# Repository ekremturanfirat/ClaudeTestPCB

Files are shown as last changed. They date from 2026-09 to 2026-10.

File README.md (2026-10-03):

# PCBDesignWClaude — 3-Phase BLDC ESC (ESP32-WROOM-32E)

KiCad project for a 3-phase brushless motor ESC.

- **MCU:** ESP32-WROOM-32E, soldered SMD directly onto the PCB (no plug-in module)
- **Input:** 12–36V DC
- **Target continuous phase current:** ~5–10A
- **Control/telemetry:** UART + CAN bus
- Design follows [METU PowerLab PCB design rules](https://github.com/odtu/Powerlab/blob/master/KiCAD/PCB_DESIGN_RULES.md)
  and uses parts exclusively from [PowerLabKiCadLibraries](https://github.com/odtu/PowerLabKiCadLibraries).

## Status
- [x] GitHub repo created
- [x] ESP32-WROOM-32E added to PowerLabKiCadLibraries (odtu/PowerLabKiCadLibraries#2, merged)
- [x] Library additions + fixes (power symbols, mounting holes, fiducials, test pads, net ties, ESP32 footprint fix): odtu/PowerLabKiCadLibraries#3 (merged)
- [x] Schematic Rev B: full rebuild per the PowerLab rules; kicad-cli ERC 0 errors, netlist verified (see [hardware/ARCHITECTURE.md](hardware/ARCHITECTURE.md))
- [x] Library fixes found during layout (exposed pads, mask margins, logo/QR graphics, ESP32 3D model): odtu/PowerLabKiCadLibraries#5 (merged)
- [x] PCB Rev B: 4 layers, 100 × 90 mm; kicad-cli DRC 0 errors / 0 unconnected / 0 parity (see [hardware/ARCHITECTURE.md](hardware/ARCHITECTURE.md#pcb-rev-b))
- [x] Fab outputs: Gerber + drill zip, BOM, position file, assembly drawings in [hardware/fab](hardware/fab/README.md)

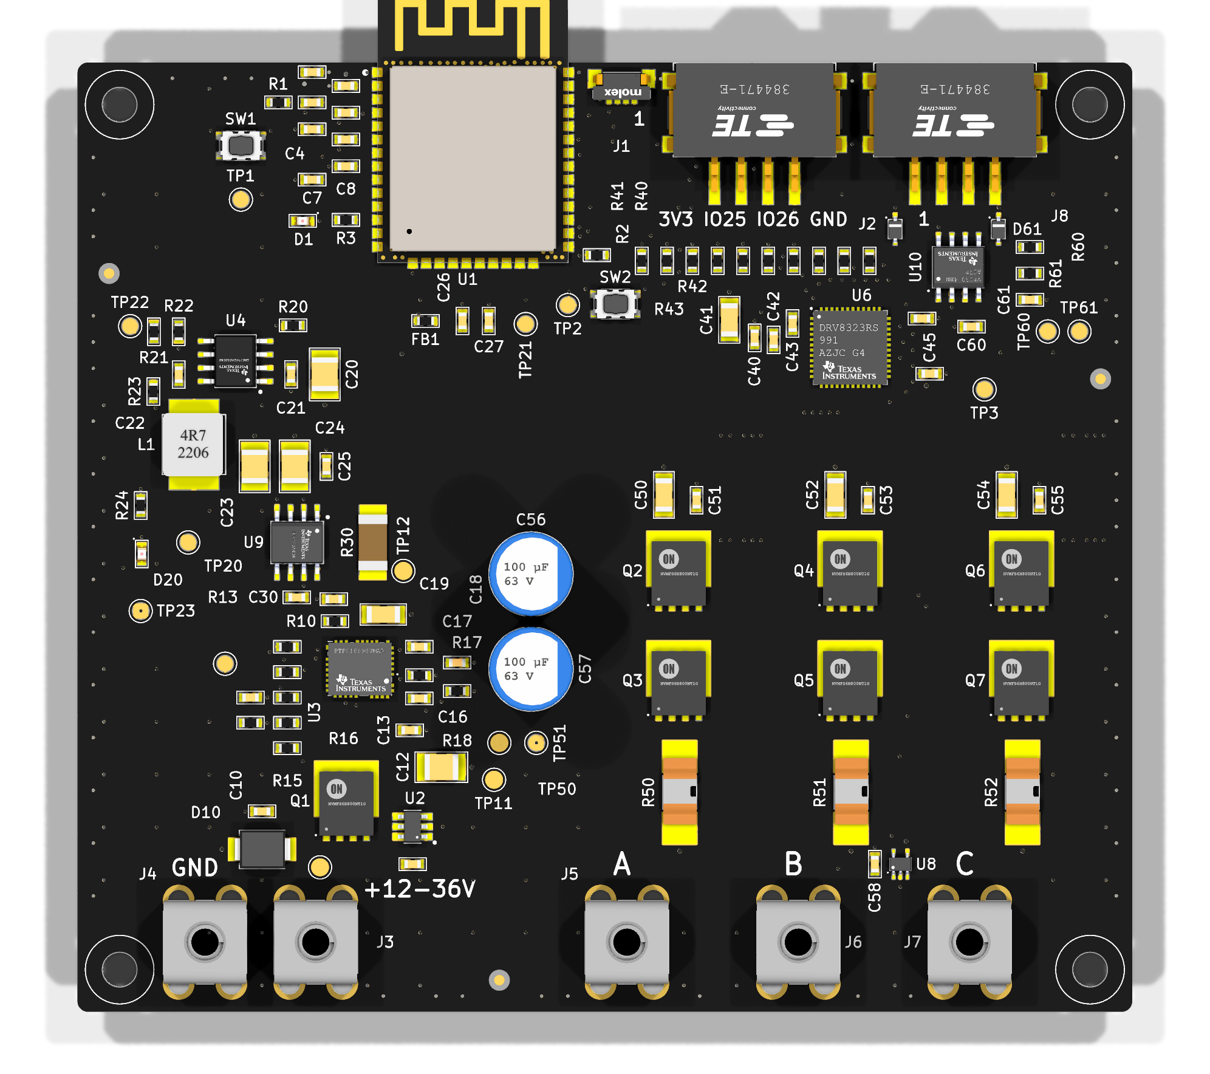
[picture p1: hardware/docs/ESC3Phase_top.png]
PCB top


## Layout
- `hardware/` — KiCad project

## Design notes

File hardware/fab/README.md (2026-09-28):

# ESC3Phase Rev B — fabrication and assembly files

Generated with kicad-cli 10.0.5 from `../ESC3Phase.kicad_pcb`. DRC with schematic parity passed with
0 errors, 0 unconnected items and 0 parity issues. Two warnings remain: the ESP32 silk outline runs over the
antenna overhang.

## Files
| File | Use |
|---|---|
| `ESC3Phase_Gerber_Drill_RevB.zip` | Upload this to PCBWay. It contains the Gerbers, the Excellon drill files (PTH and NPTH), the drill maps and the Gerber job file. |
| `gerber/` | The same files unzipped. |
| `ESC3Phase_BOM.csv` | BOM grouped by value, footprint and MPN. Columns: reference, quantity, value, manufacturer, MPN, package, SMD/THT, Digi-Key, Mouser, footprint, note. UTF-8 with BOM, so Excel shows "µ" correctly. |
| `ESC3Phase_pos.csv` | Position file (centroids) for the 102 SMD parts, top side. Units are mm; the origin is the bottom-left board corner and Y points up. |
| `ESC3Phase_assembly_top.pdf` / `_bottom.pdf` | Assembly drawings: Fab + silk + outline at 1.4×. They show the 25 references that have no room on the silkscreen. |

All outputs share one origin, the board's bottom-left corner (the drill/place origin).

## PCB order (PCBWay)
| Option | Value |
|---|---|
| Size | 100 × 90 mm, 1 mm corner radius |
| Layers | **4** (the only option above the standard-price spec, approved) |
| Stackup | 1.6 mm FR-4 TG150–160: L1 / 0.2 mm prepreg / L2 / 1.04 mm core / L3 / 0.2 mm prepreg / L4 |
| Copper | 1 oz outer, 1 oz inner |
| Min track / space | 0.15 / 0.2 mm (6/6 mil class). One 0.15 mm neck-down; everything else is ≥ 0.2 mm |
| Min hole | 0.3 mm (445 plated holes, 8 non-plated) |
| Solder mask / silk | green / white |
| Surface finish | HASL lead-free |
| Vias | tented, except the thermal vias in exposed pads, which are open on the pad side |
| Extras | none: no impedance control, castellations or blind vias |

## Assembly
- **Parts:** 109 in total, 102 SMD (all on top) and 7 THT: C56/C57 bulk caps and J3–J7 screw terminals. Only top-side paste is needed; the bottom paste layer is empty.
- **Breakaway rails needed for machine assembly.** The ESP32 antenna overhangs the top edge, and the connectors and terminals sit within 3.5 mm of the top and bottom edges. Add the rails when panelizing.
- **Fiducials:** 3 global fiducials on top.
- **BOM notes:**
  - **C3, C44 and C42 (1 µF):** order by the MPN (Murata GRM188D72A105KE01D, 0603, 100 V). The Digi-Key and Mouser numbers in the library point to a different part (a Samsung 1210). That's a library data issue.
  - **R60, R61 and C61 (CAN split termination):** fit them only on the two nodes at the ends of the bus. Leave them unfitted (DNP) on every other node.
- **Hand soldering:** power pads and the screw terminals connect solid to their pours, so use a large iron tip.

## Before ordering
- Check the Gerbers in a Gerber viewer (KiCad GerbView or PCBWay's online viewer).
- Print the layout 1:1 and check the footprints against the real parts (rule 3.7).
- Scan the QR code on the bottom silk (see `../docs/ESC3Phase_bottom.png`).

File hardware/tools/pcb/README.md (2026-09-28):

# PCB generation scripts (Rev B)

The Rev B board was built from KiCad's netlist with these scripts (KiCad 10.0.5 Python + kicad-cli,
Freerouting 2.4.1 on Java 25). They document how every placement, pour, hand-routed net and rule came about.

| Step | Script |
|---|---|
| Placement (floor plan, parts at their pins) | `placement.py`, `pcb_build.py`, `place_check.py` |
| Project file: schematic settings + board settings + net classes (HV) | `pro_merge.py` |
| Power pours, GND planes, Kelvin keep-outs, fan-out rule areas | `power.py` |
| Hand routing: DRV8323 gate drive and fan-outs, Kelvin taps, local links, GND vias | `prep_route.py` |
| Freerouting input (pours as keepouts, complete nets reduced) / session import | `dsn_prep.py`, `ses_import.py` |
| Post-route: widths, L3 GND fill + stitching, stackup, silk, board info | `fix_widths.py`, `finish_copper.py`, `stackup.py`, `silk.py`, `board_info.py` |
| Last connections (grid router with exact clearances), cleanup, 45° mitering | `maze_*.py`, `dangling.py`, `stub_clean.py`, `miter.py`, `angle_check.py` |
| Pipelines | `pipeline.sh` (build → pre-route → DRC), `post.sh`, `finish.sh` |

Paths inside the scripts point to the session working folder and the local KiCad/library install; adjust
them before re-running. Every result was verified with `kicad-cli pcb drc --schematic-parity`.

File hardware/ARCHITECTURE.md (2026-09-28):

# ESC3Phase — Architecture (Rev B)

3-phase BLDC/PMSM ESC with an ESP32-WROOM-32E soldered directly on the board. Input 12–36 V DC,
5–10 A continuous phase current, UART + CAN. Designed to the
[METU PowerLab PCB design rules](https://github.com/odtu/Powerlab/blob/master/KiCAD/PCB_DESIGN_RULES.md),
parts only from [PowerLabKiCadLibraries](https://github.com/odtu/PowerLabKiCadLibraries) (additions in
[PR #3](https://github.com/odtu/PowerLabKiCadLibraries/pull/3)).

Rev A (first attempt) was withdrawn: its schematic had real net shorts (+5V_LOGIC merged with the 36 V bus,
INHA and EFUSE_IMON merged with GND), did not follow the drawing rules, and had several datasheet errors
(listed at the end). Rev B is a full rebuild.

## Verification (kicad-cli 10.0.5)
- **ERC: 0 errors.** 11 warnings, all `pin_to_pin` "Bidirectional and Power output": the library's connector
  pins (J1, J2, J3, J4, J8) are typed `bidirectional` and sit on a net that has a `power_out` pin — a PWR_FLAG
  (VIN_RAW, +3V3_MCU) or DRV8323 pin 45 (SW of the unused internal buck, tied to GND as TI requires).
  Not a wiring fault; reported upstream as a library observation.
- **Netlist check:** KiCad's exported netlist was compared net-by-net with the intended connections of every
  pin: 79 nets, 0 shorts, 0 opens.
- Every sheet was exported to PDF and reviewed visually.

## Sheets
| Page | Sheet | Content |
|---|---|---|
| 1 | Overview (root) | specs, block diagram, revision history, sheet symbols |
| 2 | Power Input & Protection | J3/J4, SMBJ36CA, LM74700-Q1 + Q1, TPS16890 eFuse |
| 3 | Power Supply 3.3 V | LMR38020 buck, +3V3_MCU, ferrite-filtered +3V3_A, power LED |
| 4 | DC-Bus Current Sensing | 5 mΩ shunt, net-tie Kelvin taps, INA240A1 |
| 5 | MCU Core | ESP32-WROOM-32E, EN/BOOT, UART J1, expansion J2, status LED, ADC filters |
| 6 | Gate Drive | DRV8323RS with charge pump, CSA reference, pull-ups/downs |
| 7 | Power Stage | bulk caps, TMP235, 3× Half Bridge (one sub-sheet reused) |
| 8–10 | Half Bridge A/B/C | 2× NTMFS006N08MC, 2 mΩ shunt, 2 net ties, phase terminal, hot-loop caps |
| 11 | Communication | SN65HVD230, split termination, CAN ESD, J8 |

## Rails
`VIN_RAW` (connector) → `+VBUS` (after reverse-polarity FET) → `+VBUS_EFUSE` (eFuse out) → DC shunt →
`+VBUS_PROT` (motor bus, DRV8323 VM, buck input) → `+3V3_MCU` (buck) → `+3V3_A` (ferrite-filtered: DRV8323
VREF, INA240, TMP235). Single `GND`.

## Design details (datasheet references)
### Power Input — TI SNOSD17G (LM74700-Q1), SLVSHO1A (TPS1689x), Diodes DS19002 (SMBJ)
- **D10 SMBJ36CA:** 36 V standoff, 58.1 V clamp at 10.3 A. That stays below the 65 V limits of LM74700 ANODE
  and DRV8323 VM. SMBJ48CA (77.4 V clamp) was too high.
- **U2 LM74700-Q1 + Q1:** MOSFET source on the input (ANODE), drain on the output (CATHODE). EN is tied to
  ANODE. C11 100 nF sits between VCAP and ANODE; it is rated 16 V because VCAP–ANODE ≤ 15 V.
- **U3 TPS16890 eFuse** (standalone):
  - VDD filter: R10 120 Ω + C14 100 nF/100 V. TI recommends 150 Ω / 0.22 µF; these are the nearest library values.
  - UVLO: R11 866 k / R12 118 k → 10.1 V rising. The internal VIN_UV_FLT default of 10.66 V dominates.
  - Circuit breaker: R17 IMON 3.65 k → IOCP = 1 V / (18.18 µA/A × 3.65 k) = 15.1 A (Eq. 4–6). C16 22 pF.
  - ILIM: R18 1.33 k (Eq. 25, N = 1). IREF: C17 1 nF.
  - dVdT: C18 100 nF → 0.5 V/ms, about 0.13 A inrush into ~250 µF, below the 0.5 A start-up limit.
  - WP# → GND. ADDR0/ADDR1 open (address 0x40). SWEN, AUX, TEMP and NC left open.
  - SDA/SCL and PGOOD pulled up to 3.3 V. FLT → `EFUSE_NFLT` → ESP32 IO35.
  - The exposed pad is **IN**, not GND.
- Residual risk: during a surge clamped at 58 V, EN/UVLO reaches about 7 V, above its 6 V absolute maximum
  (surge only; no zener in the library).

### Power Supply — TI SNVSC40E (LMR38020)
- **Output 3.3 V directly.** The Rev A 5 V rail and NCP1117 were removed: NCP1117 needs 33 mΩ–2.2 Ω output ESR,
  which ceramic caps don't give.
- FB divider 110 k / 47 k → 3.34 V (VFB = 1.0 V).
- RT 54.9 k → about 480 kHz. At 36 V in, the on-time is 191 ns, above the 131 ns minimum.
- L1 4.7 µH / 8.1 A (Isat 7.4 A), above the 3.8 A high-side current limit.
- C23/C24 47 µF/25 V + 100 nF out; C20 4.7 µF/100 V + C21 100 nF/100 V in; CBOOT 100 nF.
- EN tied to VIN. PG pulled up to 3.3 V (TP22).

### Current Sensing — TI SBOS662C (INA240)
- R30 5 mΩ (VMP 2010) in the bus. INA240**A1** (20 V/V) → 100 mV/A, 1.5 V at 15 A.
- A4 (200 V/V) would saturate at 3.1 A. REF1/REF2 go to GND (unidirectional).
- Kelvin taps through net ties NT1/NT2.

### MCU Core — Espressif ESP32-WROOM-32E datasheet v2.1 + hardware design guidelines
- 22 µF + 100 nF at 3V3. EN: 10 k / 1 µF plus the RESET button. IO0: 10 k pull-up plus the BOOT button.
- ADC inputs are all on ADC1. Filters are 220 pF, because the INA240 and TMP235 allow at most 1 nF load.
- Strapping pins:
  - IO12 (MTDI) and IO2 carry PWM lines with 10 k pull-downs, so they read low at boot (3.3 V flash, download mode possible).
  - IO5 has a 10 k pull-up on nSCS. The DRV8323 has an internal pull-down that would otherwise fight the strap.
  - IO15 carries NFAULT with a pull-up (high = boot log enabled).
- Module pin 39 (exposed GND pad) is included in the footprint.

| Pin | Name | Net | | Pin | Name | Net |
|---|---|---|---|---|---|---|
| 2 | 3V3 | +3V3_MCU | | 23 | IO15 | NFAULT |
| 3 | EN | EN | | 24 | IO2 | PWM_AL |
| 4 | SENSOR_VP | IBUS_SENSE | | 25 | IO0 | BOOT |
| 5 | SENSOR_VN | TEMP_SENSE | | 26 | IO4 | PWM_BH |
| 6 | IO34 | ISENSE_C | | 27 | IO16 | PWM_CH |
| 7 | IO35 | EFUSE_NFLT | | 28 | IO17 | PWM_CL |
| 8 | IO32 | ISENSE_A | | 29 | IO5 | SPI_NSCS |
| 9 | IO33 | ISENSE_B | | 30 | IO18 | SPI_SCLK |
| 10 | IO25 | EXP1 | | 31 | IO19 | SPI_SDO |
| 11 | IO26 | EXP2 | | 33 | IO21 | CAN_TX |
| 12 | IO27 | LED_STATUS | | 34 | RXD0 | UART_RXD |
| 13 | IO14 | DRV_ENABLE | | 35 | TXD0 | UART_TXD |
| 14 | IO12 | PWM_BL | | 36 | IO22 | CAN_RX |
| 16 | IO13 | PWM_AH | | 37 | IO23 | SPI_SDI |
| 1, 15, 38, 39 | GND | GND | | 17–22, 32 | NC | not connected |

### Gate Drive — TI SLVSDJ3D (DRV8323RS)
- VM decoupling: 100 nF/100 V + 10 µF/100 V. VDRAIN → +VBUS_PROT.
- Charge pump: CPH–CPL 47 nF/100 V; VCP–VM 1 µF.
- DVDD: 1 µF only. It is an internal LDO output (30 mA max) and cannot supply anything else.
- **VREF is an input.** It is driven from +3V3_A with 100 nF. Rev A left it floating.
- The unused integrated buck (VIN, SW, CB, FB, nSHDN, BGND) is tied to GND (Table 9-3). CAL → GND
  (calibration is done over SPI).
- nFAULT and SDO are open-drain, with 10 k pull-ups. PWM inputs and ENABLE have 10 k pull-downs, so they
  default off.
- CSA: the default gain is 20 V/V. With 2 mΩ that gives ±0.6 V around VREF/2 at ±15 A, i.e. 1.05–2.25 V.

### Power Stage / Half Bridge — onsemi NTMFS006N08MC
- 80 V MOSFETs with 4.9 mΩ typical RDS(on). Gate drive is IDRIVE (no gate resistors).
- Low-side shunt: 2 mΩ SSA2512. Kelvin sense goes through two net ties per phase to SPx/SNx.
- Hot-loop caps per leg: 10 µF/100 V + 100 nF/100 V. Bulk: 2× 100 µF/63 V Al-polymer.
- TMP235 near the power stage, 10 mV/°C.

### Communication — TI SLOS346O (SN65HVD230)
- RS → GND (high speed). VREF open.
- Split termination 2× 56 Ω + 4.7 nF. For a multi-drop bus, mark R60/R61/C61 DNP on every node except the two ends.
- ESD: CDSOD323-T24SC (24 V) per line. SP0115 (1 V working voltage) was unsuitable.
- J8: 1 CANH, 2 CANL, 3–4 GND.

## Rev A errors fixed in Rev B
| Rev A | Problem | Rev B |
|---|---|---|
| Labels on pins, off-grid | real net shorts (+5V↔36 V bus, INHA↔GND, IMON↔GND) | wires + power symbols on the 2.54 mm grid, netlist check |
| DRV8323 VREF floating | current-sense amplifiers can't work | VREF = +3V3_A |
| DRV8323 buck pins NC | datasheet says tie to GND | tied to GND |
| INA240A4 | saturates at 3.1 A | INA240A1 |
| LM5050-1, FET reversed | not reverse-polarity protection | LM74700-Q1, source on input |
| SMBJ48CA | 77 V clamp > 65 V limits | SMBJ36CA (58 V) |
| eFuse VDD cap 16 V, pin 20/21 mix-up | over-voltage, wrong straps | 100 V cap, pins per SLVSHO1A |
| NCP1117 + 5 V rail | unstable with ceramic output caps | buck makes 3.3 V directly |
| 6.8 µH / 1.87 A inductor | below the 3.8 A current limit | 4.7 µH / 8.1 A |
| 0805 shunt part on 2010 footprint | footprint/part mismatch, no Kelvin | 2512 part, net-tie Kelvin |
| SP0115 on CAN | conducts at 1.4 V | 24 V TVS |
| Descriptions in Value fields | breaks BOM, rule 1.8 | library values |

## PCB (Rev B)
Top

### Verification (kicad-cli 10.0.5, zones refilled, schematic parity on)
- **DRC: 0 errors, 0 unconnected, 0 parity issues.**
- **Corners:** no track corner is sharper than 45° (rule 3.3). A script checks every track joint.
- **2 warnings, both explained:** the ESP32 silk outline extends past the board edge. The antenna overhangs
  the top edge on purpose, and silk off the board is simply not printed.

### Board
- **Size:** 100 × 90 mm, 1 mm corner radius, 4 × M3 NPTH holes, 3 fiducials.
- **Layers (4, approved by the user for routing density and a solid ground reference):**

  | Layer | Use |
  |---|---|
  | L1 | parts and signals |
  | L2 | solid GND plane |
  | L3 | signals, then a GND fill |
  | L4 | signals, then a GND fill |

- **Stackup:** 1.6 mm, 1 oz copper on all layers, FR-4, lead-free HASL, green mask and white silk. This is the
  PCBWay standard 4-layer spec. The 4 layers themselves are the only surcharge.

### Floor plan (rule 3.2)
- **Top edge:**
  - ESP32 module, with the antenna over the edge
  - UART header J1
  - expansion header J2
  - CAN connector J8, with the SN65HVD230 transceiver, ESD diodes and split termination below it
- **Left side:** the 3.3 V buck (LMR38020), then the INA240 with its DC-bus shunt R30.
- **Bottom left:** input terminals J4 (GND) and J3 (VIN). Power flows up through the TVS, the
  reverse-polarity FET Q1 with the LM74700 and the TPS16890 eFuse, then R30, into the bus.
- **Right side:** the DRV8323 sits above three half-bridge columns at 16.25 mm pitch. Each column has the
  high-side FET, the low-side FET, and a 2512 shunt with net-tie Kelvin taps.
  - Hot-loop caps (10 µF + 100 nF) sit right above each high-side drain.
  - Two 100 µF bulk caps sit at the left end of the bus.
  - Phase terminals J5–J7 (A/B/C) are on the bottom edge.
- **Decoupling:** every cap is at its IC pin. A placement checker enforces 1 mm pad-to-pad between parts and
  the mounting-hole keepouts, because the library parts have no courtyards.

### Copper
- **Pours (L1):**
  - `+VBUS_PROT`: a 7.5 mm band over all three drains, with a spur to the bulk caps
  - phase node plus a ~5.5 mm lane to each terminal
  - low-side source into each shunt
  - `VIN_RAW`, `+VBUS` and `+VBUS_EFUSE` along the input chain
- **GND:** L2 is solid; L1, L3 and L4 are filled. Every SMD GND pad has its own via to the plane. There are
  stitching vias on a 5 mm grid and along the edges.
- **Hand-routed DRV8323 gate drive.** Each gate runs as a pair with its own phase-sense return, with 0.6 mm to
  everything else.
  - Phase A: left pins → L1 → under the bus band on L4 → back up into the lane beside its FETs.
  - Phase C: east on L1 above the band, then the same crossing.
  - Phase B: its pins leave in the reverse order of its lane, so it runs on L4 and pops up with a via at each
    target.
  - The charge-pump, VCP and VM caps sit at their pins.
- **Other routing:**
  - Freerouting 2.4.1 routed the logic; a small grid router with exact clearances did the last four
    connections.
  - 90° corners were mitered to 45°.
  - Router neck-downs were widened to the 0.2 mm lab default, except where a fine-pitch pad needs PCBWay's
    0.15 mm floor. That applies to one segment.

### 36 V clearance (rules 2.6 / 3.3) — `ESC3Phase.kicad_dru`
- **Net class `HV`:** 0.6 mm clearance (IPC-2221B B2, outer layers, 31–100 V). It covers the bus nets
  (`VIN_RAW`, `+VBUS*`), the phases, and the gate, bootstrap and charge-pump nets. Inner layers use 0.2 mm
  (B1 allows 0.1 mm, so the fab minimum applies).
- **Waivers (documented in the rules file):**
  1. **Pads within one part.** The parts' own pad geometry is below 0.6 mm (0603 caps across the bus,
     0.5 mm-pitch QFN). Pads of different parts are ≥ 1.0 mm apart.
  2. **Fine-pitch fan-out areas (`HV_FANOUT_*` rule areas).** These cover the DRV8323 cluster, the eFuse,
     the LM74700, the buck, the TMP235 and the MOSFET gate pins. The user said to ignore the ICs for this
     rule.
  3. **HV net pairs with ≤ ~12 V between them:** gate ↔ its own phase, VCP ↔ VM, BOOT ↔ SW, LM74700 gate/VCAP
     ↔ input, shunt sense ↔ bus.

### Silkscreen and board information (rule 3.6)
- **Top:**
  - reference designators, 1.0 mm, at 0° or 90°, placed so they never cross pads, parts or labels
  - `+12-36V` / `GND` at the input
  - `A` / `B` / `C` at the phases
  - J2 pin names, and pin-1 marks on J1 and J8
- **25 references on the assembly drawing only.** In the densest spots (the ESP32 caps, eFuse passives and CAN
  ESD diodes) no legal 1.0 mm silk position exists, so these are on the F.Fab (assembly) layer only.
- **Bottom:**
  - METU PowerLab logo
  - project, Rev B and date (text variables `${PROJECT_NAME}`, `${REVISION}`, `${ISSUE_DATE}`)
  - designer, website and GitHub
  - UART and CAN pinout
  - the lab QR code, 13.3 mm, with the light modules printed so it reads with normal polarity on dark
    mask. **Scan it on a real board or render.**

### Library fixes made for this board — [PowerLabKiCadLibraries PR #5](https://github.com/odtu/PowerLabKiCadLibraries/pull/5)
| Footprint | Fix |
|---|---|
| DRV8323, TPS16890 | Mask margin 0.1 → 0.05 mm. On 0.5 mm pitch this fixes the mask bridges. |
| LMR38020 | The exposed pad was opened on both sides; it is now top only. |
| LMR38020, TPS16890, ESP32 | Thermal vias now 0.6 mm (a 0.15 mm annular ring), open on the pad side and tented underneath. |
| MOSFETs | Stray bottom paste removed. |
| New | `METUPowerLab_Graphics` library (logo, QR code) and the ESP32 STEP model from Espressif (CC-BY-SA 4.0). |

### Assembly notes
- **Breakaway rails needed.** The antenna overhang and the edge-mounted connectors put parts within 3.5 mm of
  the top and bottom edges. Machine assembly at PCBWay therefore needs breakaway rails, which are added during
  panelization.
- **Hand soldering:** power pads connect solid to their pours. The screw terminals are THT with solid
  connections, so a larger soldering iron is needed.

### Fab outputs
Gerber + drill zip, BOM, position file and assembly drawings are in [fab/](fab/README.md). All share one
origin, the board's bottom-left corner. Before ordering: check the Gerbers in a viewer, print the layout 1:1
to check the footprints, and scan the QR code.

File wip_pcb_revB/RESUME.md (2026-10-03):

# PCB Rev B — work in progress (saved 2026-09-28)

Not committed to git. Copy of the session working folder, so nothing is lost if Temp is cleaned.

## State
- 4-layer board (user-approved): L1 signal, L2 solid GND, L3 signal, L4 signal + GND fill. 100 x 90 mm.
- `pcbwork/ESC3Phase.kicad_pcb` = pre-routed board (placement, pours, hand-routed DRV8323 gate drive,
  fan-outs, GND vias). kicad-cli DRC: 0 violations, 0 parity issues, 113 connections left for Freerouting.
- Best routing so far: `route/esc7.ses` -> 2 unconnected, 20 errors (mostly GND pads seen as netless by
  the router). Fix already made in `scripts/dsn_prep.py` (GND keeps all pins; true 0.6 mm HV spacing);
  the rerun (`route/esc8.ses`) was stopped before it finished.
- Library changes for PR odtu/PowerLabKiCadLibraries#3 (not committed/pushed): `library_changes/`
  (0.05 mm mask margin on 48-VQFN + TPS16890 LQFN, ESP32 EP via pads 0.6 mm, new METUPowerLab_Graphics
  logo + QR, ESP32 STEP). Installed copies are already in Documents/KiCad/10.0/3rdparty.

## Next steps
1. `scripts/pipeline.sh` (rebuild pre-routed board) -> `dsn_prep.py <board> route/esc.dsn` ->
   Freerouting 2.4.1 (Java 25, headless: `-de route/esc.dsn -do route/esc8.ses -mp 25 -mt 6`) ->
   `scripts/post.sh route/esc8.ses` (import, widths, L3 GND + stitching, stackup, silk, DRC).
2. Fix remaining DRC errors to 0, board info (`board_info.py`: logo, QR, text, connector labels), 3D check,
   fab outputs, docs, then ask before commit/push.
Scripts expect to run from the session scratchpad layout (paths relative to the script folder).

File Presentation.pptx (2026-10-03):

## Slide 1

PCB Design Experiments with Claude
Ekrem Turan Fırat
10/2026

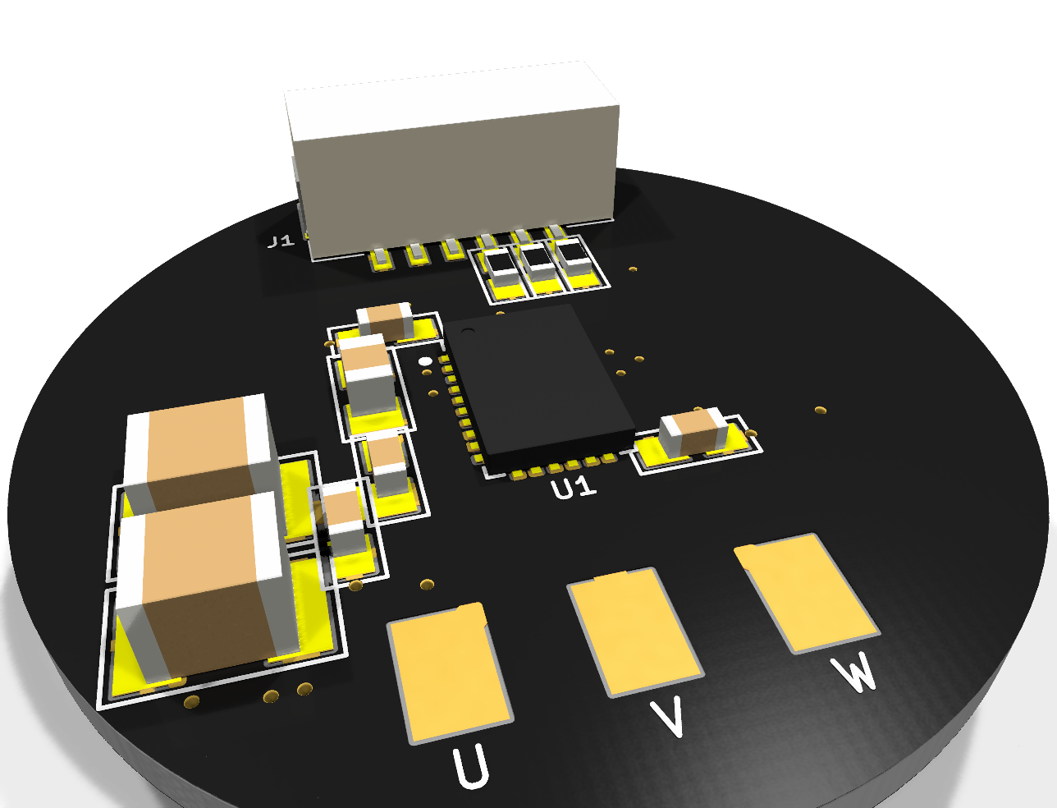
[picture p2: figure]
Mini motor driver 3D render
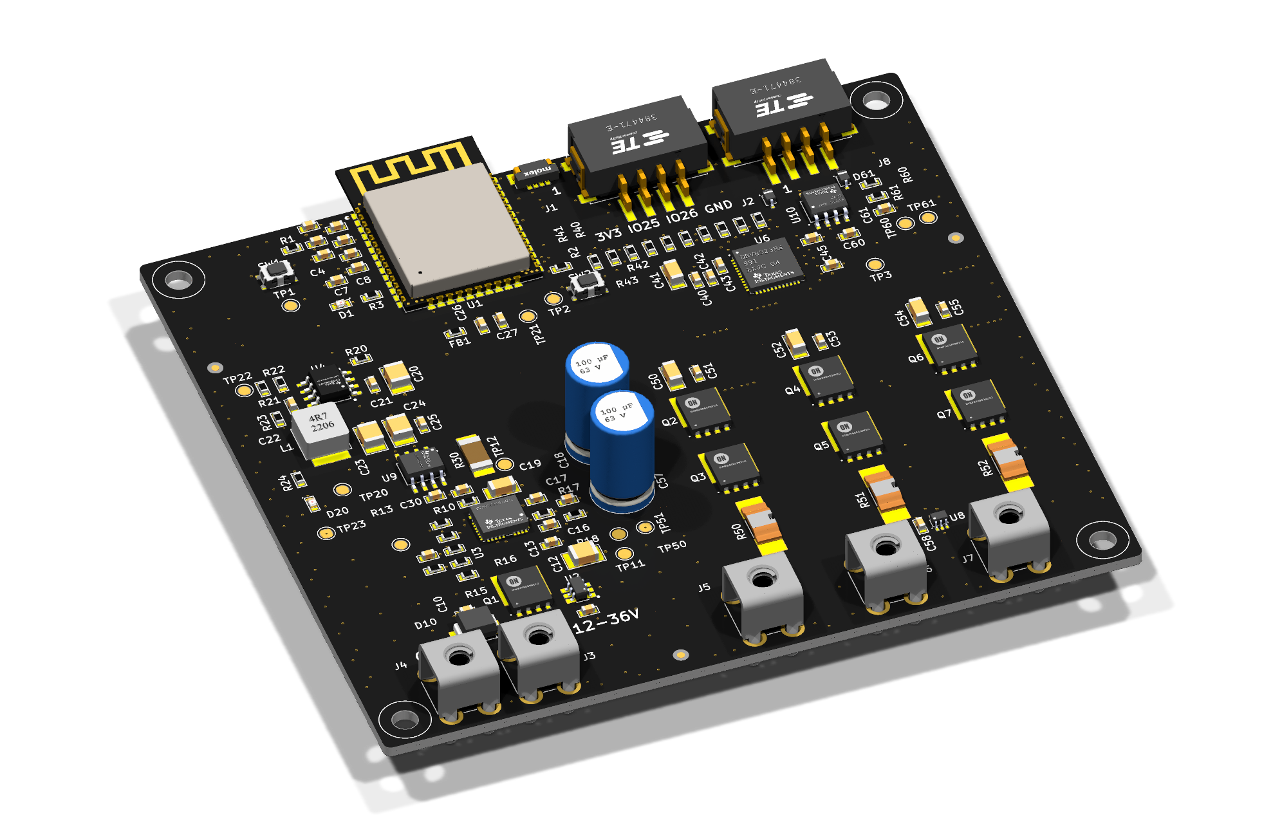
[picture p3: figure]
ESP32 ESC 3D render

## Contents

1. Logic of PCB Design with Claude
  1. Claude Desktop and KiCad Integration
  2. How the Workflow Runs
2. Mini Motor Driver(First Design Attempt)
  1. Prompt and General Infos
  2. Schematic Design
  3. PCB Design
  4. Claude’s Cost
3. Design Ruleset
  1. Schematic
  2. Fab and PCB
4. ESP32 ESC (Second Design Attempt)
  1. Prompt and General Infos
  2. Schematic Design
  3. PCB Design
  4. PCB Design Tools
  5. Library PR
  6. Claude’s Cost
5. Attempt 1 vs Attempt 2
  1. Attempt 1 vs Attempt 2

## 1.1 Claude Desktop and KiCad Integration

- KiCad MCP ( github.com/mixelpixx/ (https://github.com/mixelpixx/KiCAD-MCP-Server)KiCAD (https://github.com/mixelpixx/KiCAD-MCP-Server)-MCP-Server (https://github.com/mixelpixx/KiCAD-MCP-Server))
  - KiCad 9.0+
  - Node.js 18+
  - Python 3.11+

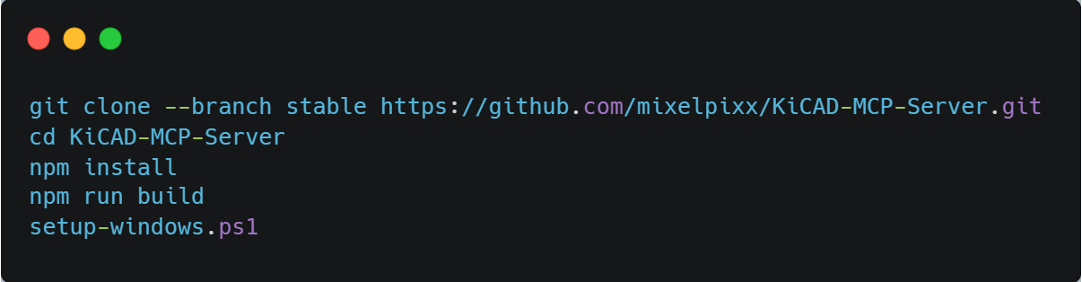
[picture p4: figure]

3

## 1.2 How the Workflow Runs

Engineer
Requirements prompt + lab design ruleset

Claude
Researches parts, does datasheet math, writes build scripts

Tool layer
KiCad MCP server, kicad-cli, KiCad Python API, Freerouting

KiCad project
Schematic, PCB, libraries and fab outputs

ERC / DRC reports, netlist checks and 3D renders go back to Claude, which fixes and re-checks until clean

4

## 2.1 First Design Attempt (Mini Motor Driver)

- Prompt: “We want to create a coin-sized 3-phase motor driver, speed must be controlled using a single signal. The driver’s IC must be all-in-one(control + gate driver + MCU).”
- Components
  - IC: MCF8315C
  - Connectors: JST GH 6-pin, Hirose DF65 3-pin
  - Libraries: symbols, footprints and 3D models generated from scratch by Claude's scripts
github.com/odtu/MiniMotorWithIntegratedDriver

5

## 2.2 Schematic Design

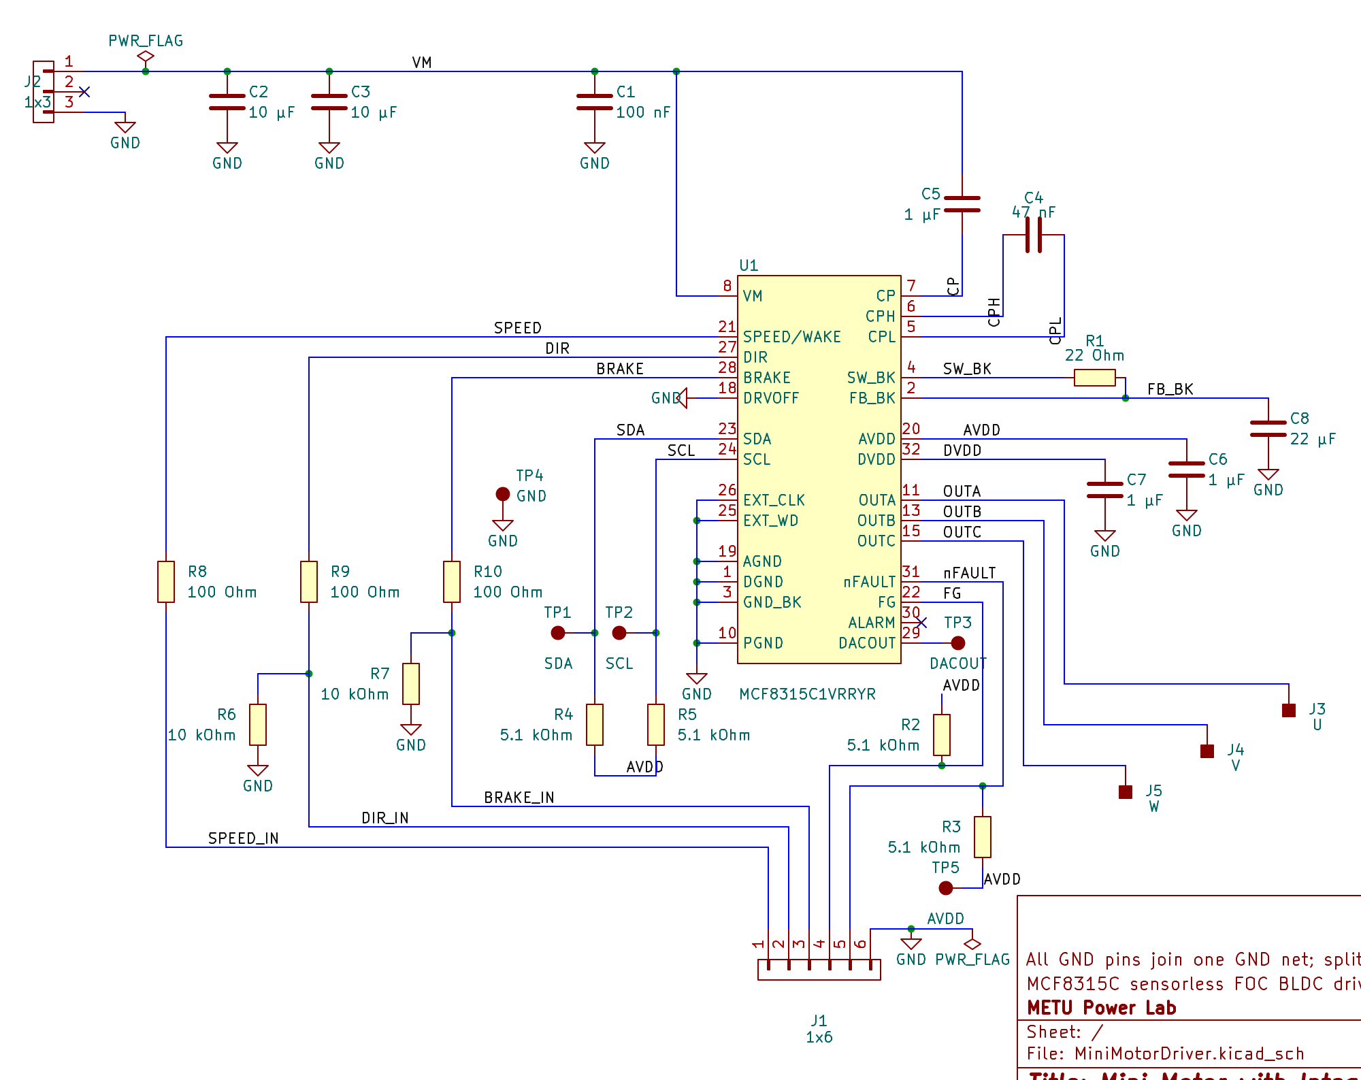
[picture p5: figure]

- U1 MCF8315C: sensorless FOC BLDC driver, control and power stage in one IC
- J2 (Hirose DF65, 3-pin): supply input with bulk and bypass caps
- J1 (JST GH, 6-pin): speed, direction and brake inputs
- U / V / W pads to the motor, test pads TP1–TP5
- One A4 sheet, cropped here to the circuit

6

## 2.3 PCB Design

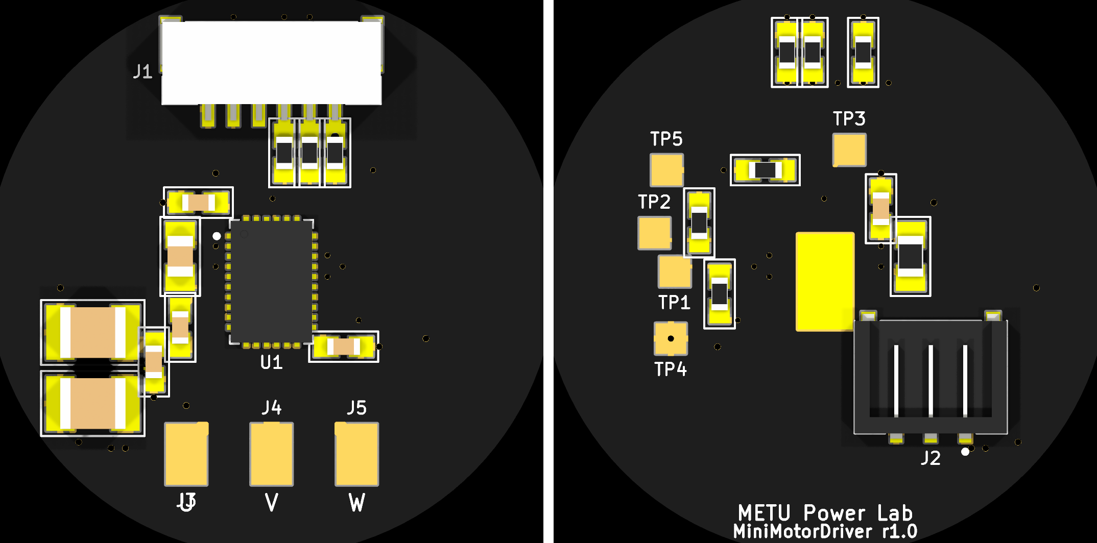
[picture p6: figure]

Top

Bottom

Ø28 mm, 4-layer board
DRC: 0 errors, 28 silkscreen warnings

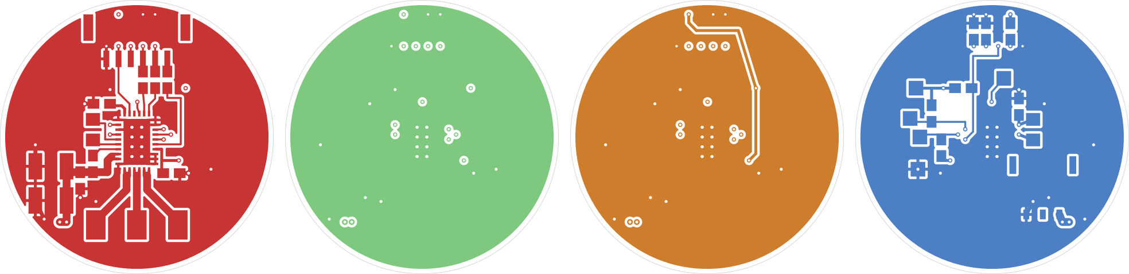
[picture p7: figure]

Top

Bottom

7

## 2.4 Claude’s Cost

$77

total cost at API rates

154.2 M

tokens processed

96.7 %

of all tokens were cache reads ($0.20 / 1M); they make up 39 % of the cost

8

## 3.1 Design Ruleset – Schematic

- Schematic Rules
  - Page setup and title block
  - Sheet structure
  - Components: PowerLabKiCadLibraries only
  - Wiring
  - Net naming and power symbols
  - Net classes and power-net styling
  - Layout notes on the schematic
  - Clean text

github.com/odtu/Powerlab/blob/master/KiCAD/PCB_DESIGN_RULES.md

9

## 3.2 Design Ruleset – PCB

- Fab limits and DRC values (PCBWay)
- PCB layout rules
  - Board setup, outline and fixed parts
  - Placement
  - Routing
  - Vias
  - Copper pours
  - Silkscreen and board information

github.com/odtu/Powerlab/blob/master/KiCAD/PCB_DESIGN_RULES.md

10

## 4.1 Second Design Attempt (ESP32 ESC)

- Prompt: “I want to create a 3-Phase ESC with ESP32-Wroom. Input voltage range must be 12-36V and continuous phase current is 5-10A. Make PCB design according to ruleset.”

Input & protection
TVS, LM74700 reverse polarity, TPS16890 eFuse

DC-bus sensing
5 mΩ shunt + INA240A1

Power stage
3 half bridges, 80 V MOSFETs

Motor
Phases A / B / C

gates

CAN + UART
SN65HVD230 transceiver

github.com/odtu/PCBDesignWClaude

ESP32-WROOM-32E
PWM, ADC, SPI, CAN

PWM

Gate driver
DRV8323RS + current-sense amps

3.3 V supply
LMR38020 buck from the bus

11

## 4.2 Schematic Design

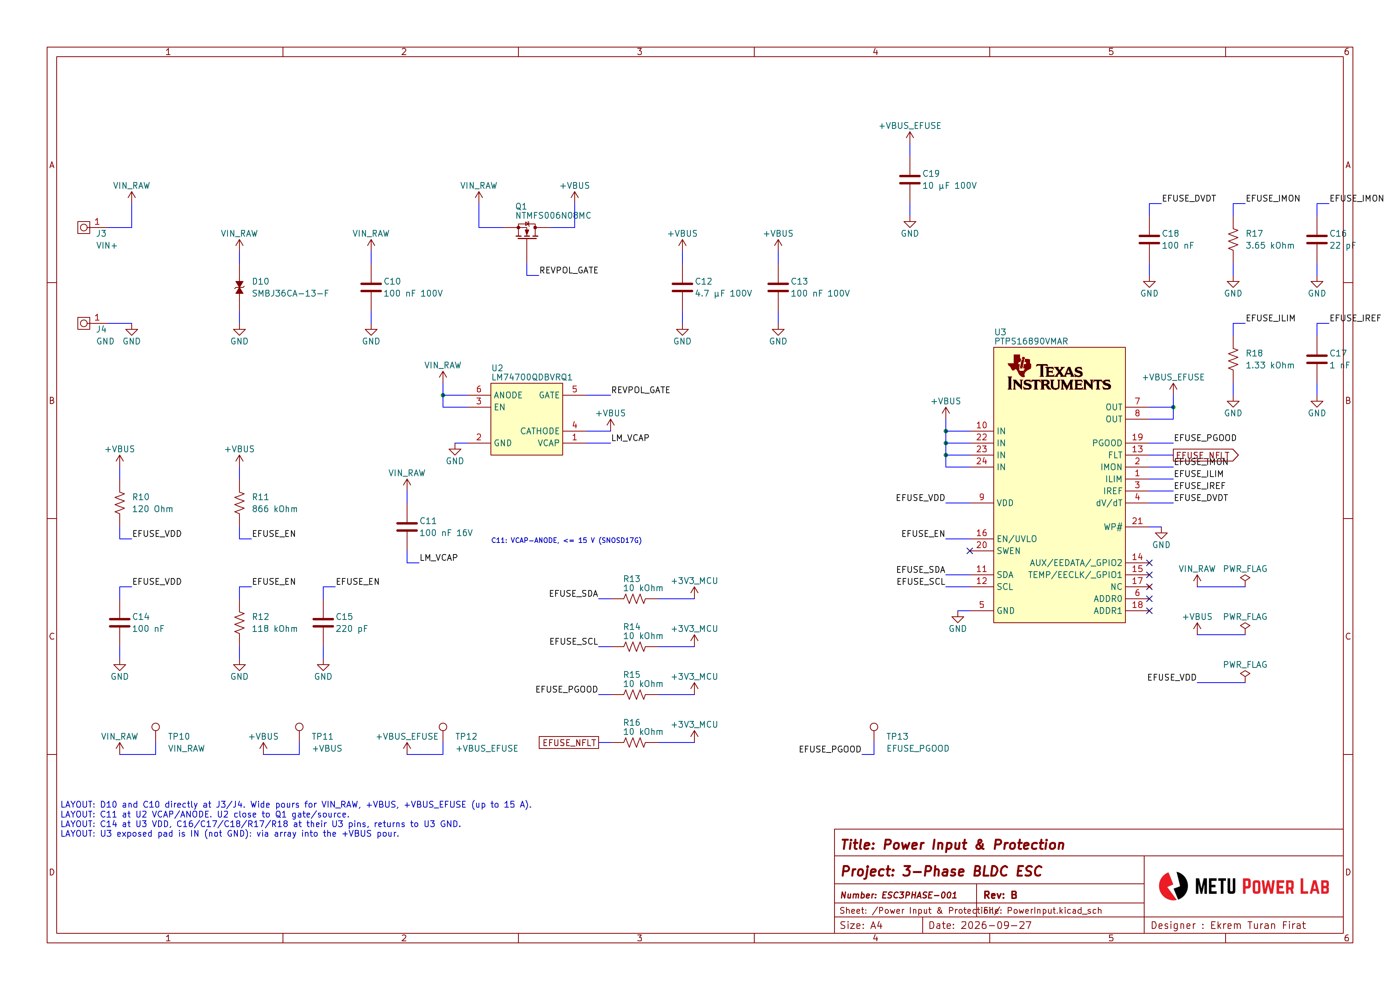
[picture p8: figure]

11 hierarchical sheets
- Overview (root)
- Power input & protection
- 3.3 V power supply
- DC-bus current sensing
- MCU core (ESP32)
- Gate drive (DRV8323RS)
- Power stage
- Half bridge A / B / C (one sheet, used 3×)
- Communication (CAN)
Checks
- ERC: 0 errors
- Netlist check: 79 nets, 0 shorts, 0 opens

12

## 4.3 PCB Design

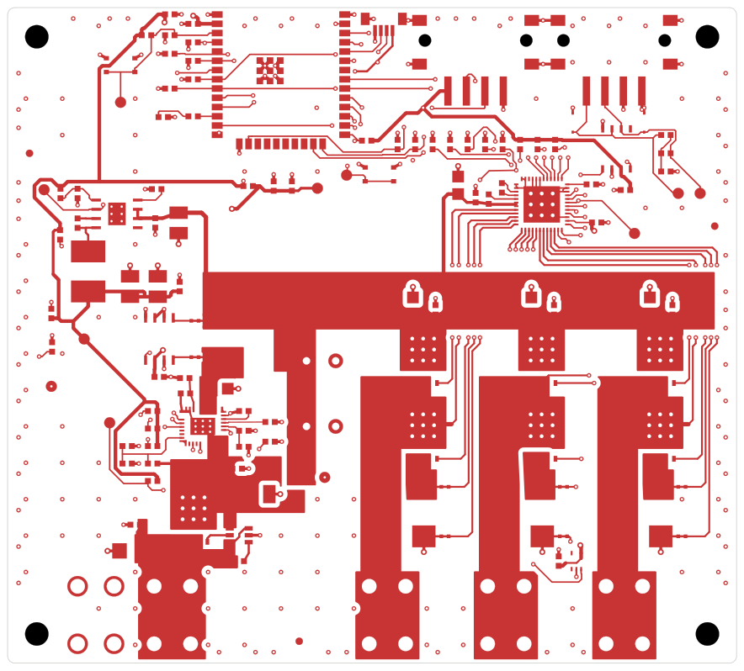
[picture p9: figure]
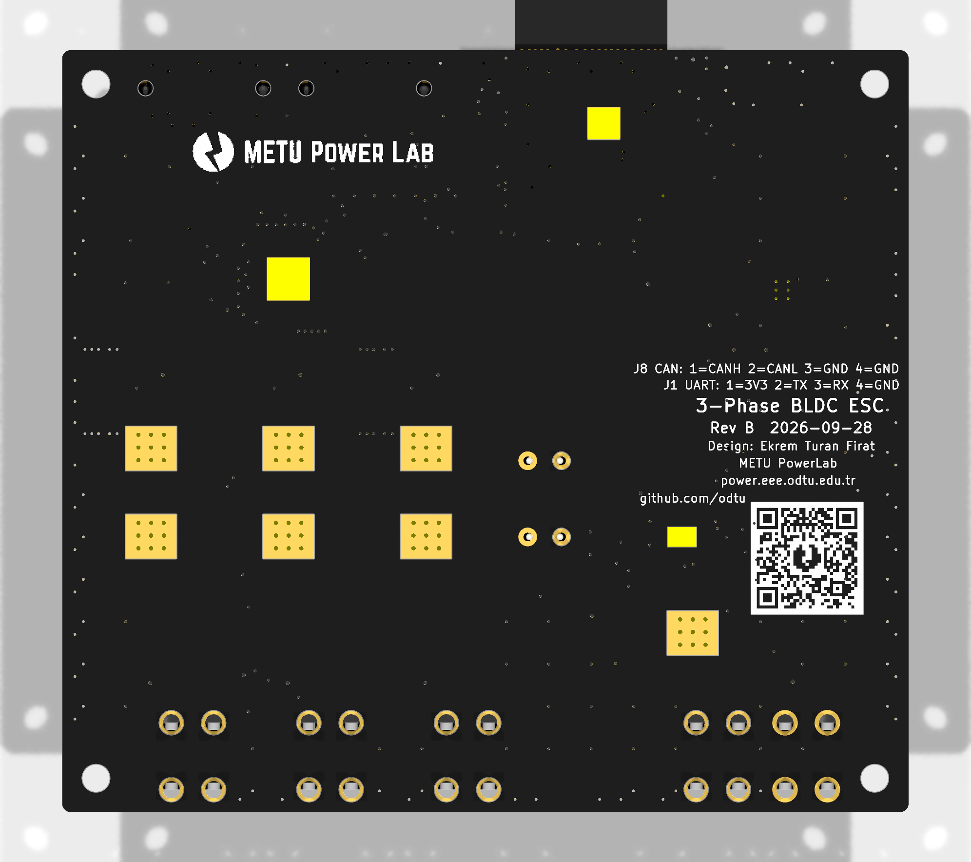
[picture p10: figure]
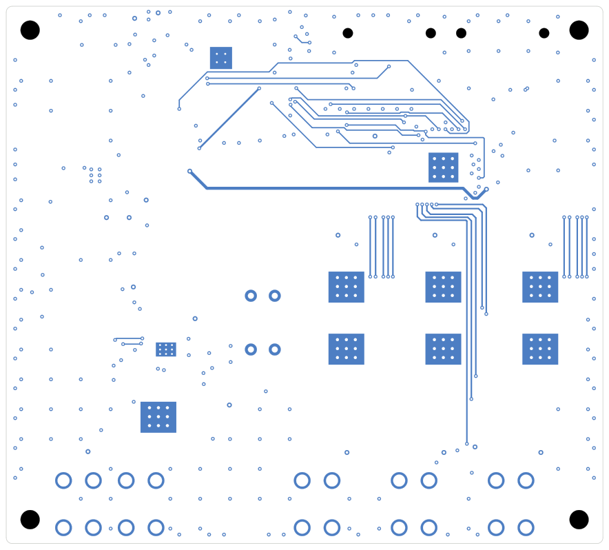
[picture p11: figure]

100 × 90 mm, 4-layer board
DRC: 0 errors, 2 silkscreen warnings

13

## 4.4 PCB Design Tools

- Freerouting 2.4.1
- Java 25

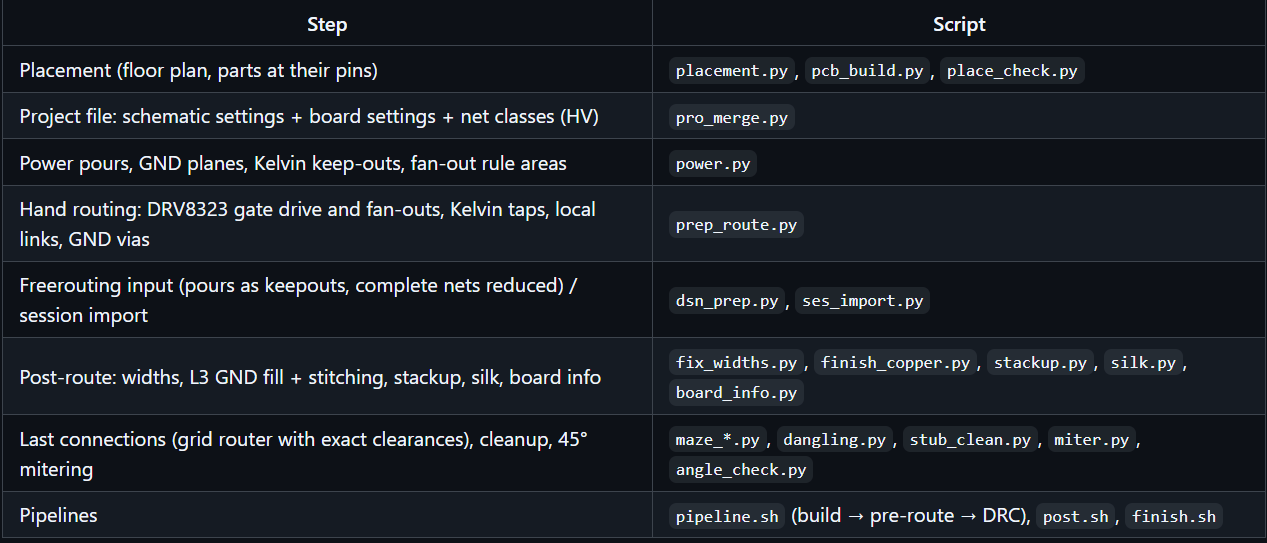
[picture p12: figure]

github.com/ekremturanfirat/ClaudeTestPCB/tree/main/hardware/tools/pcb

14

## 4.5 Library Contributions

Parts that were missing or wrong in PowerLabKiCadLibraries were fixed at the source during the ESC work. All three pull requests are merged.

PR #2
New part
- ESP32-WROOM-32E symbol and footprint
- Needed for the ESC's MCU

merged

PR #3
Additions and fixes
- Power symbols, mounting holes, fiducials
- Test pads and net ties
- ESP32 footprint fix

merged

PR #5
Fixes found during layout
- Mask margin 0.1 → 0.05 mm on 0.5 mm-pitch QFNs
- Exposed pads and 0.6 mm thermal vias
- Logo + QR graphics, ESP32 3D model

merged

github.com/odtu/PowerLabKiCadLibraries

15

## 4.7 Claude’s Cost

$167

total cost at API rates

540 M

tokens processed

98.6 %

of all tokens were cache reads ($0.20 / 1M); they make up 64 % of the cost

16

## 5.1 Attempt 1 vs Attempt 2

| Attempt 1: Mini Motor Driver | Attempt 2: ESP32 ESC
Board | Ø28 mm, 4 layers | 100 × 90 mm, 4 layers
Footprints on board | 29 | 141
Schematic | 1 sheet | 11 sheets (hierarchical)
Lab design ruleset | Not used | Used
DRC result | 0 errors, 28 silkscreen warnings | 0 errors, 2 silkscreen warnings
Design Time | 10 Hours | 10 Hours
Tokens | 154 M | 540 M
Cost at API rates | $77 | $167

17

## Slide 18

Thank you
Q/A

github.com/odtu/PCBDesignWClaude
github.com/odtu/MiniMotorWithIntegratedDriver

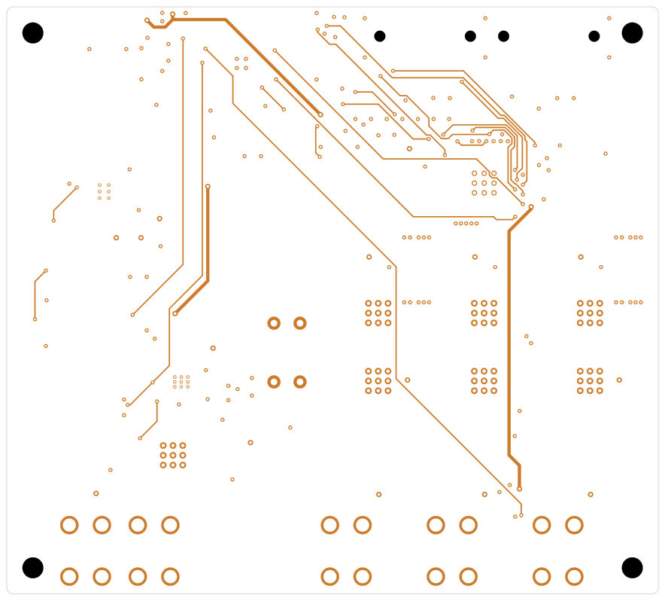
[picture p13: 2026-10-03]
wip_pcb_revB/render4/ESC3Phase_routed_L3_inner.png

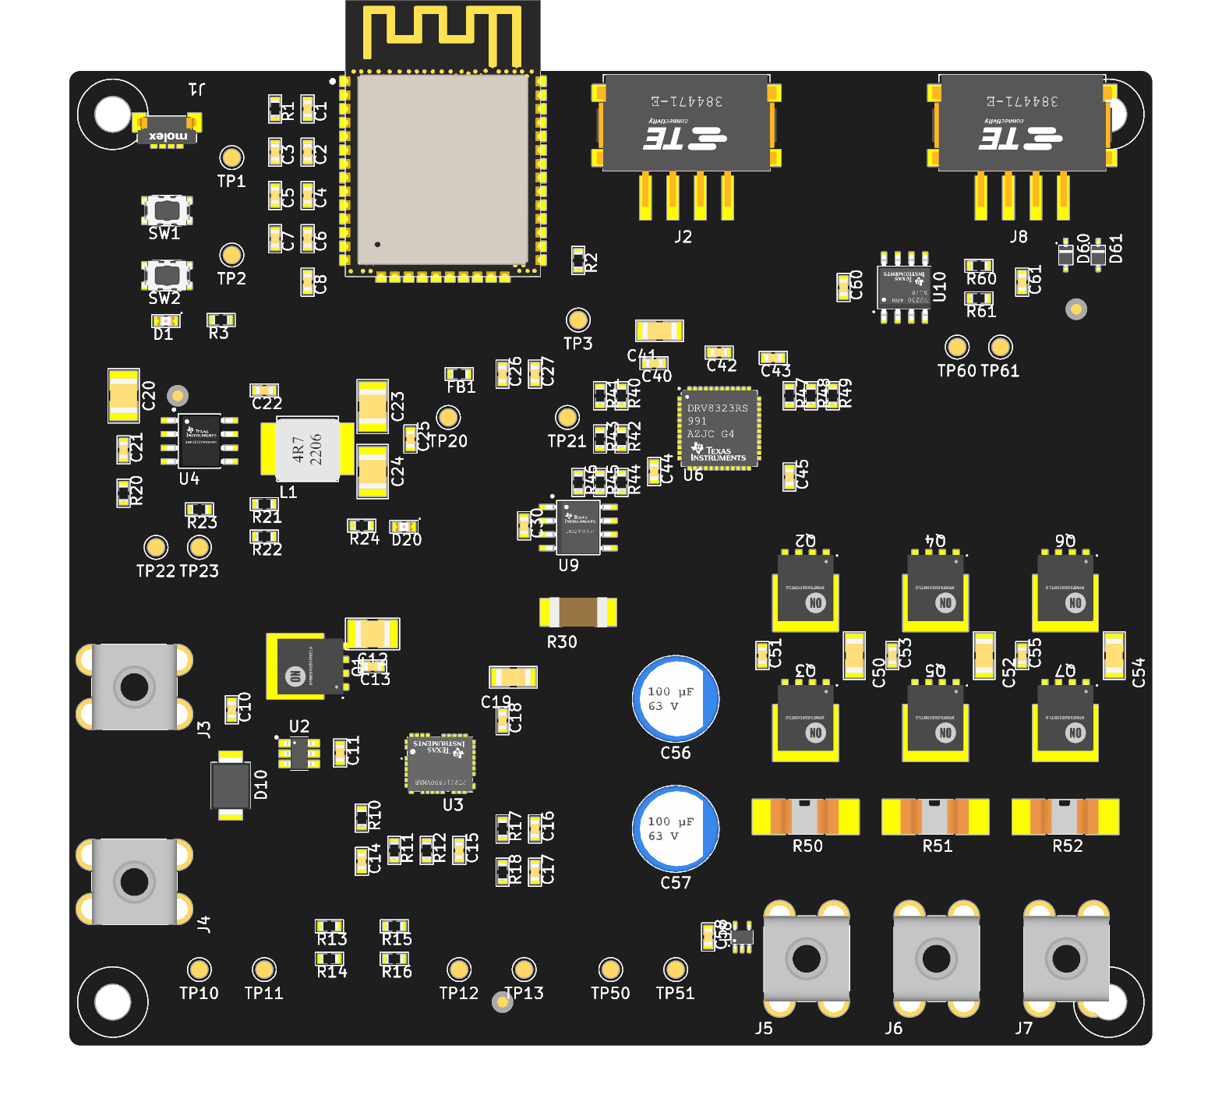
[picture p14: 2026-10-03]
wip_pcb_revB/pcbwork/render_top.png

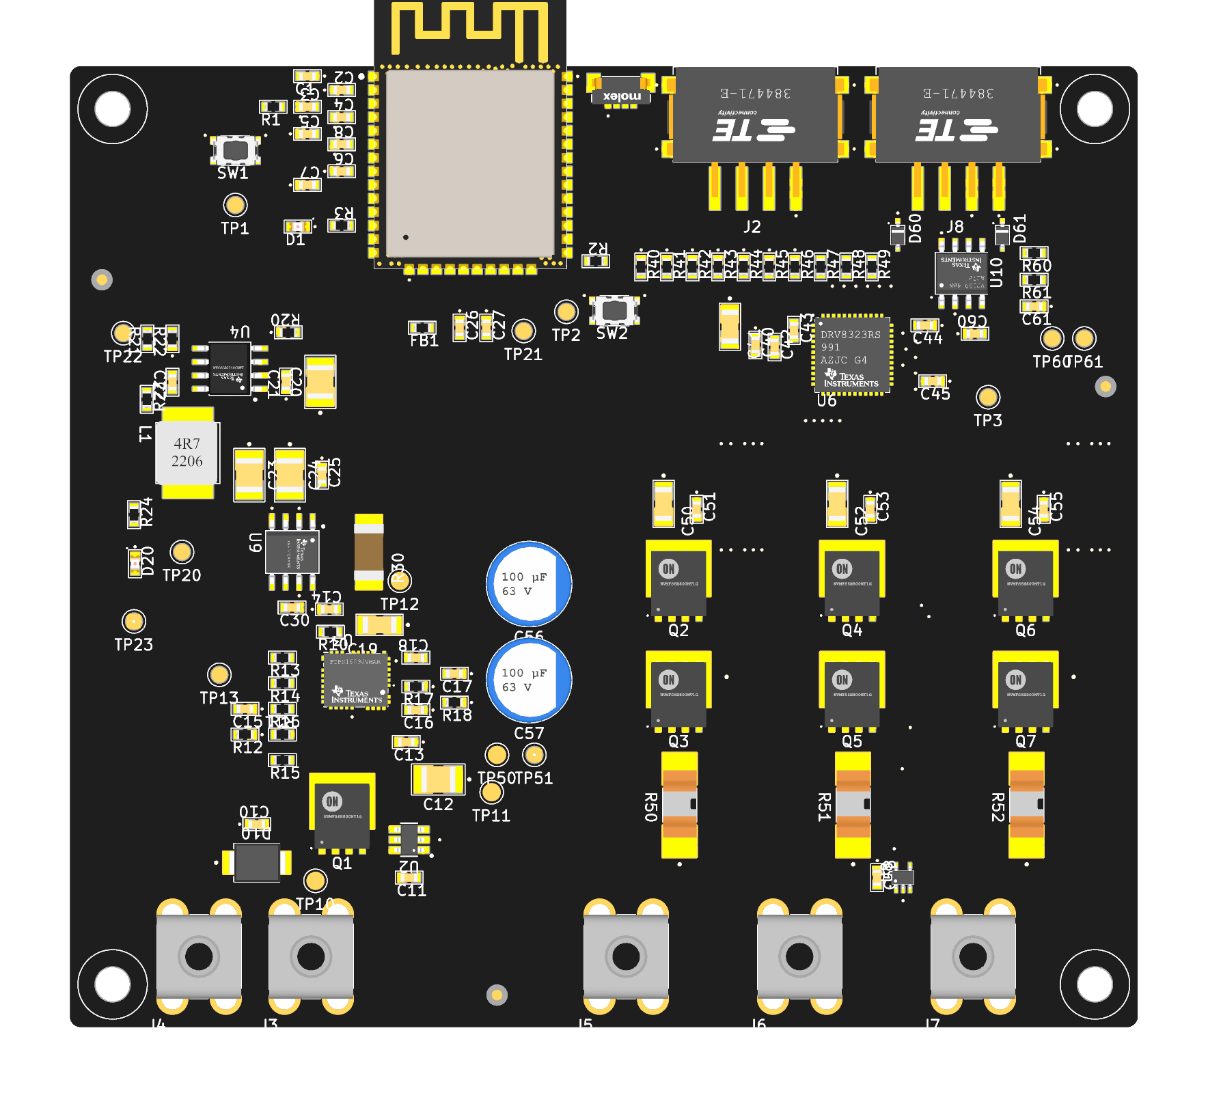
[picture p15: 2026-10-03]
wip_pcb_revB/render4/ESC3Phase_3D_top.png

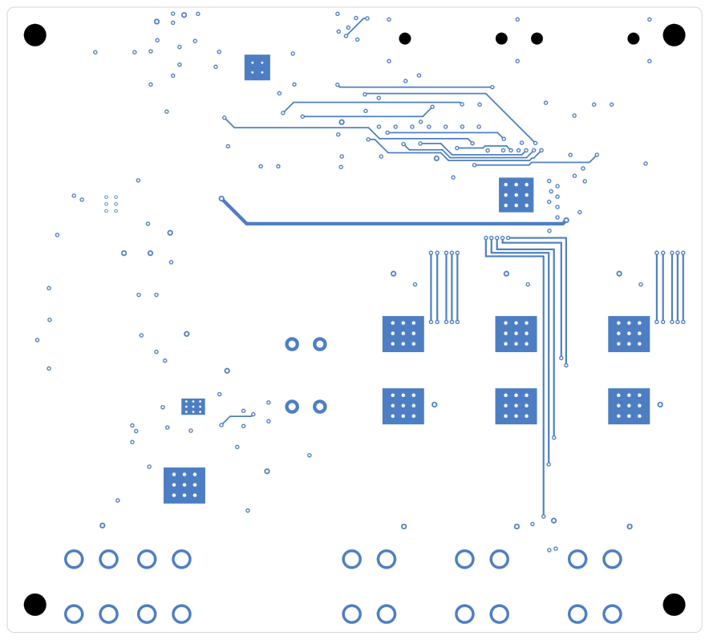
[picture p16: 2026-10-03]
wip_pcb_revB/render4/ESC3Phase_routed_L4_bottom.png

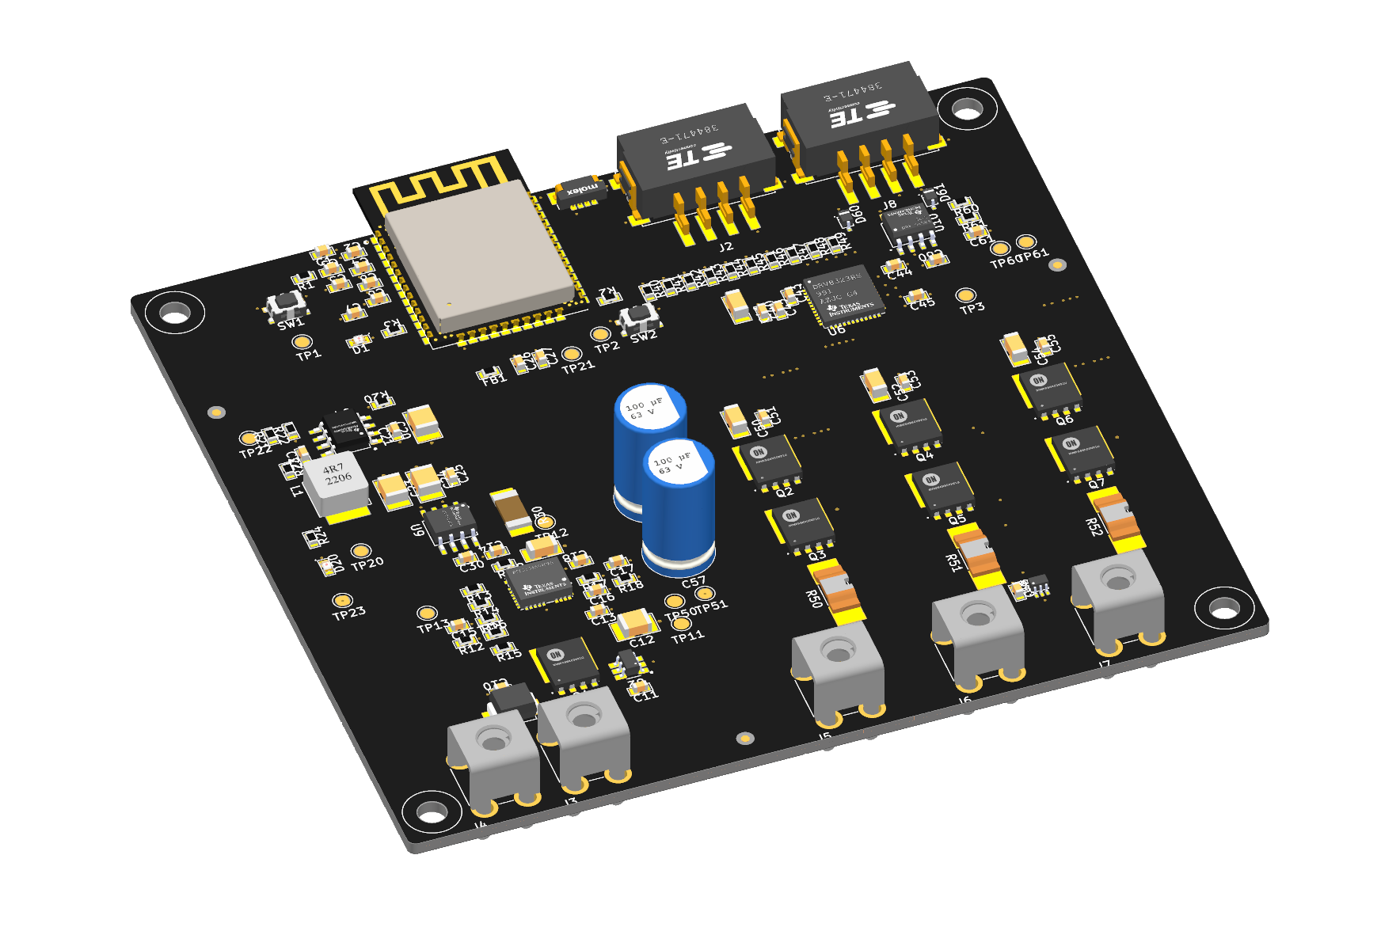
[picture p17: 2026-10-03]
wip_pcb_revB/render4/ESC3Phase_3D_iso.png

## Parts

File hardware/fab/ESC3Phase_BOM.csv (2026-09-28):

Reference | Qty | Value | Manufacturer | MPN | Package | SMD/THT | Digi-Key | Mouser | Footprint | Note
C1 | 1 | 22 µF | Samsung Electro-Mechanics | CL10A226MP8NUNE | 0603 (1608 Metric) | Surface Mount | 1276-1274-1-ND | 187-CL10A226MP8NUNE | METUPowerLab_Capacitors_Ceramics_SurfaceMounts:0603_Medium
C2,C18,C22,C25,C27,C30,C45,C58,C60 | 9 | 100 nF | YAGEO | CC0603KRX7R7BB104 | 0603 (1608 Metric) | Surface Mount | 311-1088-1-ND | 603-CC603KRX7R7BB104 | METUPowerLab_Capacitors_Ceramics_SurfaceMounts:0603_Medium
C3,C44 | 2 | 1 µF | Murata Electronics | GRM188D72A105KE01D | 0603 (1608Metric) | Surface Mount | 1276-2883-1-ND | 187-CL32B105KCJSNNE | METUPowerLab_Capacitors_Ceramics_SurfaceMounts:0603_Medium | Order by MPN: library Digi-Key/Mouser numbers are for a different (Samsung 1210) part
C4,C5,C6,C7,C8,C15 | 6 | 220 pF | Samsung Electro-Mechanics | CL10B221JB8NNNC | 0603 (1608 Metric) | Surface Mount | 1276-1985-1-ND | 187-CL10B221JB8NNNC | METUPowerLab_Capacitors_Ceramics_SurfaceMounts:0603_Medium
C10,C13,C21,C40,C51,C53,C55 | 7 | 100 nF 100V | Samsung Electro-Mechanics | CL10B104KC8NNNC | 0603 (1608 Metric) | Surface Mount | 1276-6807-1-ND | 187-CL10B104KC8NNNC | METUPowerLab_Capacitors_Ceramics_SurfaceMounts:0603_Medium
C11 | 1 | 100 nF 16V | YAGEO | CC0603KRX7R7BB104 | 0603 (1608 Metric) | Surface Mount | 311-1088-1-ND | 603-CC603KRX7R7BB104 | METUPowerLab_Capacitors_Ceramics_SurfaceMounts:0603_Medium
C12,C20 | 2 | 4.7 µF 100V | Samsung Electro-Mechanics | CL32Y475MCIVPNE | 1210 (3225 Metric) | Surface Mount | 1276-CL32Y475MCIVPNECT-ND | 187-CL32Y475MCIVPNE | METUPowerLab_Capacitors_Ceramics_SurfaceMounts:1210_Medium
C14 | 1 | 100 nF | Samsung Electro-Mechanics | CL10B104KC8NNNC | 0603 (1608 Metric) | Surface Mount | 1276-6807-1-ND | 187-CL10B104KC8NNNC | METUPowerLab_Capacitors_Ceramics_SurfaceMounts:0603_Medium
C16 | 1 | 22 pF | Samsung Electro-Mechanics | CL10C220JB8NFNC | 0603 (1608 Metric) | Surface Mount | 1276-2228-1-ND |  | METUPowerLab_Capacitors_Ceramics_SurfaceMounts:0603_Medium
C17 | 1 | 1 nF | Murata Electronics | GCM1885C2A102JA16D | 0603 (1608Metric) | Surface Mount | 490-4772-1-ND | 81-GCM1885C2A102JA6D | METUPowerLab_Capacitors_Ceramics_SurfaceMounts:0603_Medium
C19,C41,C50,C52,C54 | 5 | 10 µF 100V | TDK Corporation | C3216X6S2A106K160AC | 1206(3206 Metric) | Surface Mount | 445-C3216X6S2A106K160ACCT-ND | 810-C3216X6S2A106K16 | METUPowerLab_Capacitors_Ceramics_SurfaceMounts:1206_Medium
C23,C24 | 2 | 47 µF | Taiyo Yuden | TMK325ABJ476MM-T | 1210 (3225 Metric) | Surface Mount | 587-6156-1-ND | TMK325ABJ476MM | METUPowerLab_Capacitors_Ceramics_SurfaceMounts:1210_Medium
C26 | 1 | 10 µF | Samsung Electro-Mechanics | CL10A106MP8NNNC | 0603 (1608 Metric) | Surface Mount | 1276-1871-1-ND | 187-CL10A106MP8NNNC | METUPowerLab_Capacitors_Ceramics_SurfaceMounts:0603_Medium
C42 | 1 | 1 µF 100V | Murata Electronics | GRM188D72A105KE01D | 0603 (1608Metric) | Surface Mount | 1276-2883-1-ND | 187-CL32B105KCJSNNE | METUPowerLab_Capacitors_Ceramics_SurfaceMounts:0603_Medium | Order by MPN: library Digi-Key/Mouser numbers are for a different (Samsung 1210) part
C43 | 1 | 47 nF 100V | Würth Elektronik | 885012206118 | 0603 (1608 Metric) | Surface Mount | 732-12192-1-ND | 710-885012206118 | METUPowerLab_Capacitors_Ceramics_SurfaceMounts:0603_Medium
C56,C57 | 2 | 100 µF 63V | Cornell Dubilier Knowles | 107AVG063MFBJ | 8.00*13.50mm | Through Hole | 1572-1656-ND | 598-107AVG063MFBJ | METUPowerLab_Capacitors_AluminumPolymers_ThroughHoles:8.00x13.50mm
C61 | 1 | 4.7 nF | Murata Electronics | GCM188R72A472KA37D | 0603 (1608 Metric) | Surface Mount | 490-4930-1-ND | 81-GCM188R72A472K37D | METUPowerLab_Capacitors_Ceramics_SurfaceMounts:0603_Medium | CAN split termination: fit only on the two bus-end nodes (DNP otherwise)
D1,D20 | 2 | Green | Würth Elektronik | 150060GS75000 | 0603 (1608 Metric) | Surface Mount | 732-4971-1-ND | 710-150060GS75000 | METUPowerLab_LEDs_SurfaceMounts:0603_Medium
D10 | 1 | SMBJ36CA-13-F | Diodes Incorporated | SMBJ36CA-13-F | DO-214AA (SMB) | Surface Mount | SMBJ36CA-FDICT-ND | 621-SMBJ36CA-13-F | METUPowerLab_Diodes_TVSDiodes:DO-214AA
D60,D61 | 2 | CDSOD323-T24SC | Diodes Incorporated | CDSOD323-T24SC | SOD-323 | Surface Mount | CDSOD323-T24SCCT-ND | 652-CDSOD323-T24SC | METUPowerLab_Diodes_TVSDiodes:SOD-323
FB1 | 1 | BLM18EG221SN1D | Murata Electronics | BLM18EG221SN1D | 0603 (1608 Metric) | Surface Mount | 490-3992-1-ND | 81-BLM18EG221SN1D | METUPowerLab_CircuitProtections_FerriteBeads:0603_Medium
J1 | 1 | UART | Molex | 2147210040 |  | Surface Mount, Right Angle | 900-2147210040CT-ND | 538-214721-0040 | METUPowerLab_Connectors_SignalConnectors:2147210040
J2 | 1 | EXPANSION | TE Connectivity Erni | 384471-E |  | Surface Mount, Right Angle | 2684-384471-ECT-ND | 305-384471 | METUPowerLab_Connectors_SignalConnectors:384471-E
J3 | 1 | VIN+ | Keystone Electronics | 7770 |  | Through Hole | 36-7770-ND | 534-7770 | METUPowerLab_Connectors_ScrewTerminals:7770
J4 | 1 | GND | Keystone Electronics | 7770 |  | Through Hole | 36-7770-ND | 534-7770 | METUPowerLab_Connectors_ScrewTerminals:7770
J5,J6,J7 | 3 | PHASE | Keystone Electronics | 7770 |  | Through Hole | 36-7770-ND | 534-7770 | METUPowerLab_Connectors_ScrewTerminals:7770
J8 | 1 | CAN | TE Connectivity Erni | 384471-E |  | Surface Mount, Right Angle | 2684-384471-ECT-ND | 305-384471 | METUPowerLab_Connectors_SignalConnectors:384471-E
L1 | 1 | 4.7µH | Eaton - Electronics Division | EXLA1V0505-4R7-R |  | Surface Mount | 283-EXLA1V0505-4R7-RCT-ND | 704-EXLA1V0505-4R7-R | METUPowerLab_Inductors_SurfaceMounts:6x5_7mm
Q1,Q2,Q3,Q4,Q5,Q6,Q7 | 7 | NTMFS006N08MC | onsemi | NTMFS006N08MC | 8-PowerTDFN(5x6) | Surface Mount | 488-NTMFS006N08MCCT-ND | 863-NTMFS006N08MC | METUPowerLab_Transistors_MOSFETs:8-PowerTDFN(5x6mm)
R1,R2,R13,R14,R15,R16,R40,R41,R42,R43,R44,R45,R46,R47,R48,R49 | 16 | 10 kOhm | YAGEO | RC0603FR-0710KL | 0603 (1608 Metric) | Surface Mount | 311-10.0KHRCT-ND | 603-RC0603FR-0710KL | METUPowerLab_Resistors_ChipResistors:0603_Medium
R3,R24 | 2 | 1 kOhm | Stackpole Electronics Inc | RMCF0603FT1K00 | 0603 (1608 Metric) | Surface Mount | RMCF0603FT1K00CT-ND | 708-RMCF0603FT1K00 | METUPowerLab_Resistors_ChipResistors:0603_Medium
R10 | 1 | 120 Ohm | Stackpole Electronics Inc | RMCF0603FT120R | 0603 (1608 Metric) | Surface Mount | RMCF0603FT120RCT-ND | 708-RMCF0603FT120R | METUPowerLab_Resistors_ChipResistors:0603_Medium
R11 | 1 | 866 kOhm | Stackpole Electronics Inc | RMCF0603FT866K | 0603 (1608 Metric) | Surface Mount | RMCF0603FT866KCT-ND | 708-RMCF0603FT866K | METUPowerLab_Resistors_ChipResistors:0603_Medium
R12 | 1 | 118 kOhm | Stackpole Electronics Inc | RMCF0603FT118K | 0603 (1608 Metric) | Surface Mount | RMCF0603FT118KCT-ND | 708-RMCF0603FT118K | METUPowerLab_Resistors_ChipResistors:0603_Medium
R17 | 1 | 3.65 kOhm | Stackpole Electronics Inc | RMCF0603FT3K65 | 0603 (1608 Metric) | Surface Mount | 738-RMCF0603FT3K65CT-ND | 708-RMCF0603FT3K65 | METUPowerLab_Resistors_ChipResistors:0603_Medium
R18 | 1 | 1.33 kOhm | Stackpole Electronics Inc | RMCF0603FT1K33 | 0603 (1608 Metric) | Surface Mount | RMCF0603FT1K33CT-ND | 708-RMCF0603FT1K33 | METUPowerLab_Resistors_ChipResistors:0603_Medium
R20 | 1 | 54.9 kOhm | Stackpole Electronics Inc | RMCF0603FT54K9 | 0603 (1608 Metric) | Surface Mount | RMCF0603FT54K9CT-ND | 708-RMCF0603FT54K9 | METUPowerLab_Resistors_ChipResistors:0603_Medium
R21 | 1 | 110 kOhm | Stackpole Electronics Inc | RMCF0603FT110K | 0603 (1608 Metric) | Surface Mount | RMCF0603FT110KCT-ND | 708-RMCF0603FT110K | METUPowerLab_Resistors_ChipResistors:0603_Medium
R22 | 1 | 47 kOhm | Stackpole Electronics Inc | RMCF0603FT47K0 | 0603 (1608 Metric) | Surface Mount | RMCF0603FT47K0CT-ND | 708-RMCF0603FT47K0 | METUPowerLab_Resistors_ChipResistors:0603_Medium
R23 | 1 | 100 kOhm | Stackpole Electronics Inc | RMCF0603FT100K | 0603 (1608 Metric) | Surface Mount | RMCF0603FT100KCT-ND | 708-RMCF0603FT100K | METUPowerLab_Resistors_ChipResistors:0603_Medium
R30 | 1 | 5 mOhm | Isabellenhuette USA | VMP-R005-1.0-U | 2010 (5025 Metric) | Surface Mount | 4423-VMP-R005-1.0-UCT-ND |  | METUPowerLab_Resistors_ShuntResistors:2010
R50,R51,R52 | 3 | 2 mOhm | Littelfuse Inc. | SSA2512LR002JWR | 2512 (6432 Metric) | Surface Mount | 18-SSA2512LR002JWRCT-ND | 576-SSA2512LR002JWR | METUPowerLab_Resistors_ShuntResistors:2512
R60,R61 | 2 | 56 Ohm | Stackpole Electronics Inc | RMCF0603FT56R0 | 0603 (1608 Metric) | Surface Mount | RMCF0603FT56R0CT-ND | 708-RMCF0603FT56R0 | METUPowerLab_Resistors_ChipResistors:0603_Medium | CAN split termination: fit only on the two bus-end nodes (DNP otherwise)
SW1 | 1 | RESET | E-Switch | TL6330AF200Q | 3.7*2.8mm | Surface Mount | EG5546CT-ND | 612-TL6330AF200Q | METUPowerLab_Switches_TactileSwitches:TL6330AF200Q
SW2 | 1 | BOOT | E-Switch | TL6330AF200Q | 3.7*2.8mm | Surface Mount | EG5546CT-ND | 612-TL6330AF200Q | METUPowerLab_Switches_TactileSwitches:TL6330AF200Q
U1 | 1 | ESP32-WROOM-32E | Espressif Systems | ESP32-WROOM-32E-N4 | Module 18x25.5mm | Surface Mount | 1965-ESP32-WROOM-32E-N4CT-ND | 356-ESP32WRM32E132PH | METUPowerLab_Microcontrollers_ESP32:ESP32-WROOM-32E
U2 | 1 | LM74700QDBVRQ1 | Texas Instruments | LM74700QDBVRQ1 | SOT-23-6 | Surface Mount | 296-LM74700QDBVRQ1CT-ND | 595-LM74700QDBVRQ1 | METUPowerLab_CircuitProtections_IdealDiodes:SOT-23-6_DBV
U3 | 1 | PTPS16890VMAR | Texas Instruments | PTPS16890VMAR |  | Surface Mount |  |  | METUPowerLab_CircuitProtections_eFuses:23-LQFN-CLIP_(VMA)
U4 | 1 | LMR38020FSDDAR | Texas Instruments | LMR38020FSDDAR | 8-SOICPower | Surface Mount | 296-LMR38020FSDDARCT-ND | 595-LMR38020FSDDAR | METUPowerLab_Regulators_BuckConverters:8-SOICPower
U6 | 1 | DRV8323RSRGZT | Texas Instruments | DRV8323RSRGZT | 48-VQFN | Surface Mount | 296-46943-1-ND | 595-DRV8323RSRGZT | METUPowerLab_MotorDrivers_BLDC:48-VQFN
U8 | 1 | TMP235A4DCKR | Texas Instruments | TMP235A4DCKR | SC-70-5 | Surface Mount | 296-50016-1-ND | TMP235A4DCKR | METUPowerLab_Sensors_Temperature:SC-70-5
U9 | 1 | INA240A1DR | Texas Instruments | INA240A1DR | 8-SOIC | Surface Mount | 296-51172-1-ND | 595-INA240A1DR | METUPowerLab_Amplifiers_CurrentSenses:8-SOIC
U10 | 1 | SN65HVD230DR | Texas Instruments | SN65HVD230DR | 8-SOIC | Surface Mount | 296-11654-1-ND | 595-SN65HVD230DR | METUPowerLab_Interfaces_CANBusBridges:8-SOIC

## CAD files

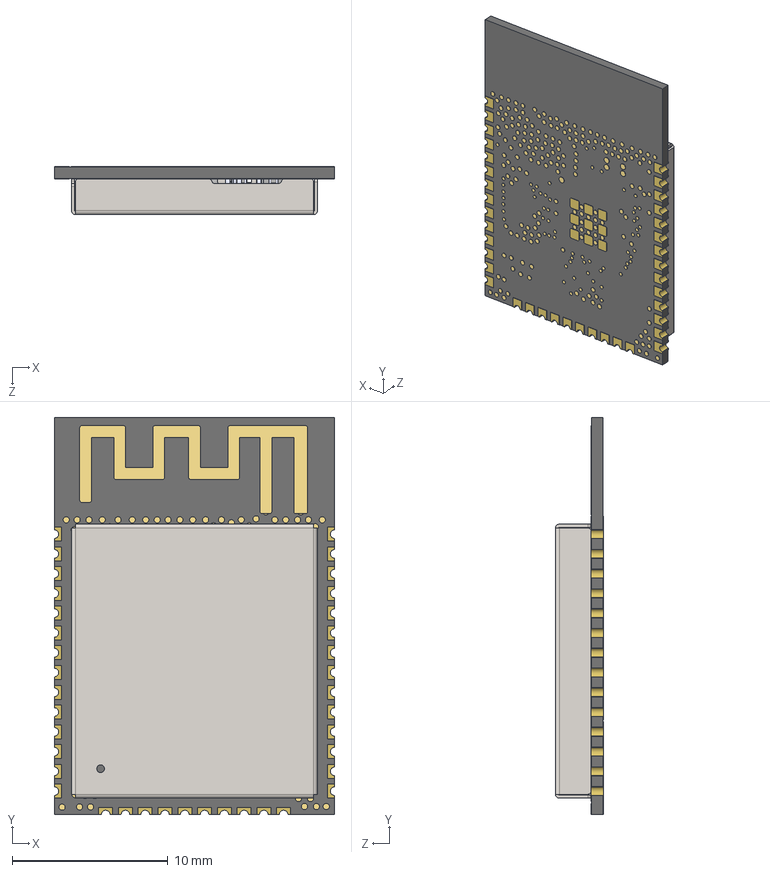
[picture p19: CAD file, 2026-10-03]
wip_pcb_revB/library_changes/3d_Microcontrollers/METUPowerLab_Microcontrollers_ESP32_ESP32-WROOM-32E.step
18.0 x 25.5 x 3.10 mm
ESP32_5x5_20210301.STEP^ESP32_5x5_20210301.STEP_Submodel-SLP48_5X5_part_DesignRootModel_PCB_ESP32-WROOM-32E_V1(2)_PCB_ESP32-WROOM-32E_V1
trace_1^Submodel-ANT_L_TYPEA_1501846164_part_DesignRootModel_PCB_ESP32-WROOM-32E_V1(2)_PCB_ESP32-WROOM-32E_V1
DFN1006.STEP^DFN1006.STEP_Submodel-SOD882_part_DesignRootModel_PCB_ESP32-WROOM-32E_V1(2)_PCB_ESP32-WROOM-32E_V1
R0201_20210301.STEP^R0201_20210301.STEP_Submodel-R0201_part_DesignRootModel_PCB_ESP32-WROOM-32E_V1(2)_PCB_ESP32-WROOM-32E_V1 x 3
L0201_20210301.STEP^L0201_20210301.STEP_Submodel-L0201_part_DesignRootModel_PCB_ESP32-WROOM-32E_V1(2)_PCB_ESP32-WROOM-32E_V1 x 2
C0201_20210301.STEP^C0201_20210301.STEP_Submodel-C0201_part_DesignRootModel_PCB_ESP32-WROOM-32E_V1(2)_PCB_ESP32-WROOM-32E_V1 x 17
SOIC8_208_20210301.STEP^SOIC8_208_20210301.STEP_Submodel-SOIC08-WN_part_DesignRootModel_PCB_ESP32-WROOM-32E_V1(2)_PCB_ESP32-WROOM-32E_V1
XTAL3225_20210301.STEP^XTAL3225_20210301.STEP_Submodel-3225_part_DesignRootModel_PCB_ESP32-WROOM-32E_V1(2)_PCB_ESP32-WROOM-32E_V1
C0402_20210301.STEP^C0402_20210301.STEP_Submodel-0402A_part_DesignRootModel_PCB_ESP32-WROOM-32E_V1(2)_PCB_ESP32-WROOM-32E_V1 x 2
uid__1-311^DesignRootModel_PCB_ESP32-WROOM-32E_V1(2)_PCB_ESP32-WROOM-32E_V1
uid__1-312^DesignRootModel_PCB_ESP32-WROOM-32E_V1(2)_PCB_ESP32-WROOM-32E_V1
uid__1-313^DesignRootModel_PCB_ESP32-WROOM-32E_V1(2)_PCB_ESP32-WROOM-32E_V1
uid__1-314^DesignRootModel_PCB_ESP32-WROOM-32E_V1(2)_PCB_ESP32-WROOM-32E_V1
uid__1-315^DesignRootModel_PCB_ESP32-WROOM-32E_V1(2)_PCB_ESP32-WROOM-32E_V1
uid__1-316^DesignRootModel_PCB_ESP32-WROOM-32E_V1(2)_PCB_ESP32-WROOM-32E_V1
uid__1-317^DesignRootModel_PCB_ESP32-WROOM-32E_V1(2)_PCB_ESP32-WROOM-32E_V1
uid__1-318^DesignRootModel_PCB_ESP32-WROOM-32E_V1(2)_PCB_ESP32-WROOM-32E_V1
uid__1-319^DesignRootModel_PCB_ESP32-WROOM-32E_V1(2)_PCB_ESP32-WROOM-32E_V1
uid__1-320^DesignRootModel_PCB_ESP32-WROOM-32E_V1(2)_PCB_ESP32-WROOM-32E_V1
uid__1-321^DesignRootModel_PCB_ESP32-WROOM-32E_V1(2)_PCB_ESP32-WROOM-32E_V1
uid__1-322^DesignRootModel_PCB_ESP32-WROOM-32E_V1(2)_PCB_ESP32-WROOM-32E_V1
uid__1-323^DesignRootModel_PCB_ESP32-WROOM-32E_V1(2)_PCB_ESP32-WROOM-32E_V1
uid__1-324^DesignRootModel_PCB_ESP32-WROOM-32E_V1(2)_PCB_ESP32-WROOM-32E_V1
uid__1-325^DesignRootModel_PCB_ESP32-WROOM-32E_V1(2)_PCB_ESP32-WROOM-32E_V1
uid__1-326^DesignRootModel_PCB_ESP32-WROOM-32E_V1(2)_PCB_ESP32-WROOM-32E_V1
uid__1-327^DesignRootModel_PCB_ESP32-WROOM-32E_V1(2)_PCB_ESP32-WROOM-32E_V1
uid__1-328^DesignRootModel_PCB_ESP32-WROOM-32E_V1(2)_PCB_ESP32-WROOM-32E_V1
uid__1-329^DesignRootModel_PCB_ESP32-WROOM-32E_V1(2)_PCB_ESP32-WROOM-32E_V1
uid__1-330^DesignRootModel_PCB_ESP32-WROOM-32E_V1(2)_PCB_ESP32-WROOM-32E_V1
uid__1-331^DesignRootModel_PCB_ESP32-WROOM-32E_V1(2)_PCB_ESP32-WROOM-32E_V1
uid__1-332^DesignRootModel_PCB_ESP32-WROOM-32E_V1(2)_PCB_ESP32-WROOM-32E_V1
uid__1-333^DesignRootModel_PCB_ESP32-WROOM-32E_V1(2)_PCB_ESP32-WROOM-32E_V1
uid__1-334^DesignRootModel_PCB_ESP32-WROOM-32E_V1(2)_PCB_ESP32-WROOM-32E_V1
uid__1-335^DesignRootModel_PCB_ESP32-WROOM-32E_V1(2)_PCB_ESP32-WROOM-32E_V1
uid__1-336^DesignRootModel_PCB_ESP32-WROOM-32E_V1(2)_PCB_ESP32-WROOM-32E_V1
uid__1-337^DesignRootModel_PCB_ESP32-WROOM-32E_V1(2)_PCB_ESP32-WROOM-32E_V1
uid__1-338^DesignRootModel_PCB_ESP32-WROOM-32E_V1(2)_PCB_ESP32-WROOM-32E_V1
uid__1-339^DesignRootModel_PCB_ESP32-WROOM-32E_V1(2)_PCB_ESP32-WROOM-32E_V1
uid__1-340^DesignRootModel_PCB_ESP32-WROOM-32E_V1(2)_PCB_ESP32-WROOM-32E_V1
uid__1-341^DesignRootModel_PCB_ESP32-WROOM-32E_V1(2)_PCB_ESP32-WROOM-32E_V1
uid__1-342^DesignRootModel_PCB_ESP32-WROOM-32E_V1(2)_PCB_ESP32-WROOM-32E_V1
uid__1-343^DesignRootModel_PCB_ESP32-WROOM-32E_V1(2)_PCB_ESP32-WROOM-32E_V1
uid__1-344^DesignRootModel_PCB_ESP32-WROOM-32E_V1(2)_PCB_ESP32-WROOM-32E_V1
uid__1-345^DesignRootModel_PCB_ESP32-WROOM-32E_V1(2)_PCB_ESP32-WROOM-32E_V1
uid__1-346^DesignRootModel_PCB_ESP32-WROOM-32E_V1(2)_PCB_ESP32-WROOM-32E_V1
uid__1-347^DesignRootModel_PCB_ESP32-WROOM-32E_V1(2)_PCB_ESP32-WROOM-32E_V1
uid__1-348^DesignRootModel_PCB_ESP32-WROOM-32E_V1(2)_PCB_ESP32-WROOM-32E_V1
uid__1-349^DesignRootModel_PCB_ESP32-WROOM-32E_V1(2)_PCB_ESP32-WROOM-32E_V1
uid__1-350^DesignRootModel_PCB_ESP32-WROOM-32E_V1(2)_PCB_ESP32-WROOM-32E_V1
uid__1-351^DesignRootModel_PCB_ESP32-WROOM-32E_V1(2)_PCB_ESP32-WROOM-32E_V1
uid__1-352^DesignRootModel_PCB_ESP32-WROOM-32E_V1(2)_PCB_ESP32-WROOM-32E_V1
uid__1-353^DesignRootModel_PCB_ESP32-WROOM-32E_V1(2)_PCB_ESP32-WROOM-32E_V1
uid__1-354^DesignRootModel_PCB_ESP32-WROOM-32E_V1(2)_PCB_ESP32-WROOM-32E_V1
uid__1-355^DesignRootModel_PCB_ESP32-WROOM-32E_V1(2)_PCB_ESP32-WROOM-32E_V1
uid__1-356^DesignRootModel_PCB_ESP32-WROOM-32E_V1(2)_PCB_ESP32-WROOM-32E_V1
uid__1-357^DesignRootModel_PCB_ESP32-WROOM-32E_V1(2)_PCB_ESP32-WROOM-32E_V1
uid__1-359^DesignRootModel_PCB_ESP32-WROOM-32E_V1(2)_PCB_ESP32-WROOM-32E_V1
uid__1-360^DesignRootModel_PCB_ESP32-WROOM-32E_V1(2)_PCB_ESP32-WROOM-32E_V1
uid__1-361^DesignRootModel_PCB_ESP32-WROOM-32E_V1(2)_PCB_ESP32-WROOM-32E_V1
uid__1-362^DesignRootModel_PCB_ESP32-WROOM-32E_V1(2)_PCB_ESP32-WROOM-32E_V1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

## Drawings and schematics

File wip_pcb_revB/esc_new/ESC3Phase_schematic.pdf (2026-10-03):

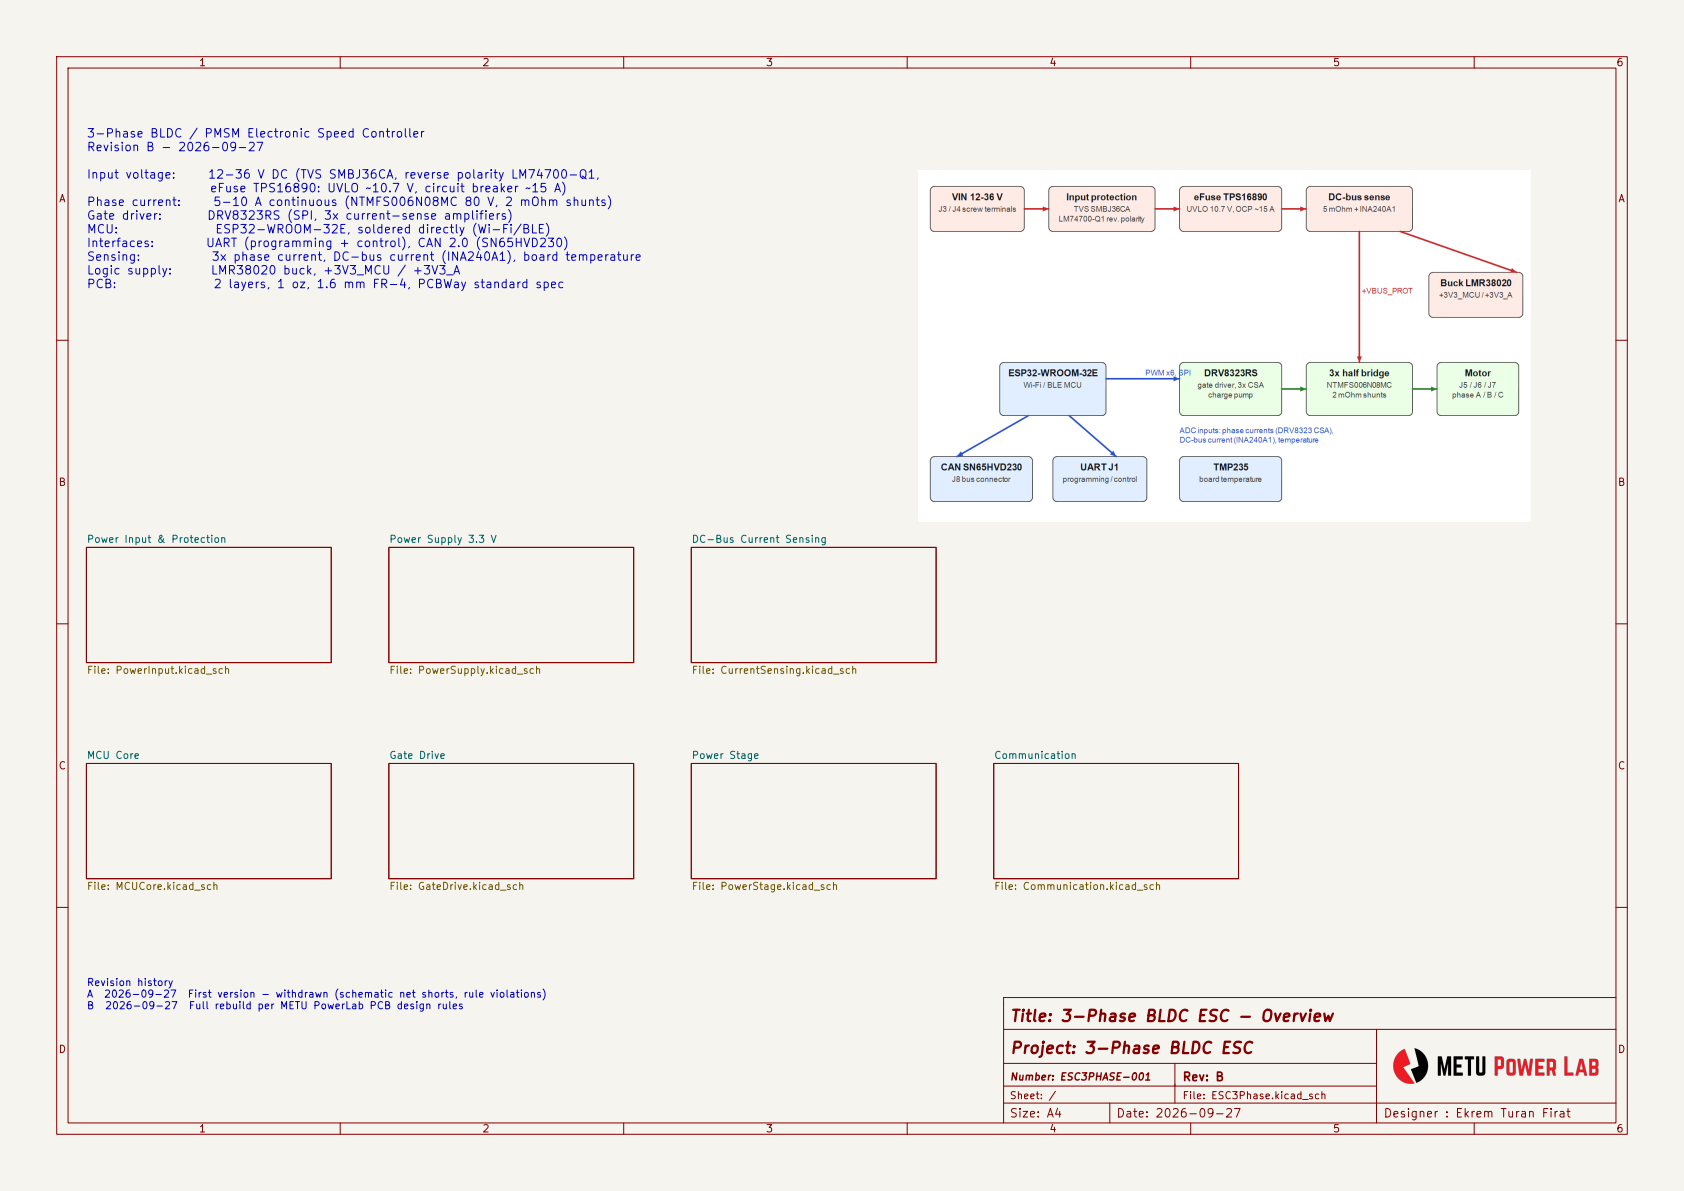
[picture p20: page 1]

3-Phase BLDC / PMSM Electronic Speed Controller
Revision B - 2026-09-27

eFuse TPS16890: UVLO ~10.7 V, circuit breaker ~15 A)

File: GateDrive.kicad_sch Power Supply 3.3 V

File: PowerSupply.kicad_sch Power Input & Protection

File: PowerInput.kicad_sch MCU Core

File: Communication.kicad_sch Power Stage

Revision history A 2026-09-27 First version - withdrawn (schematic net shorts, rule violations) B 2026-09-27 Full rebuild per METU PowerLab PCB design rules

Title: 3-Phase BLDC ESC - Overview

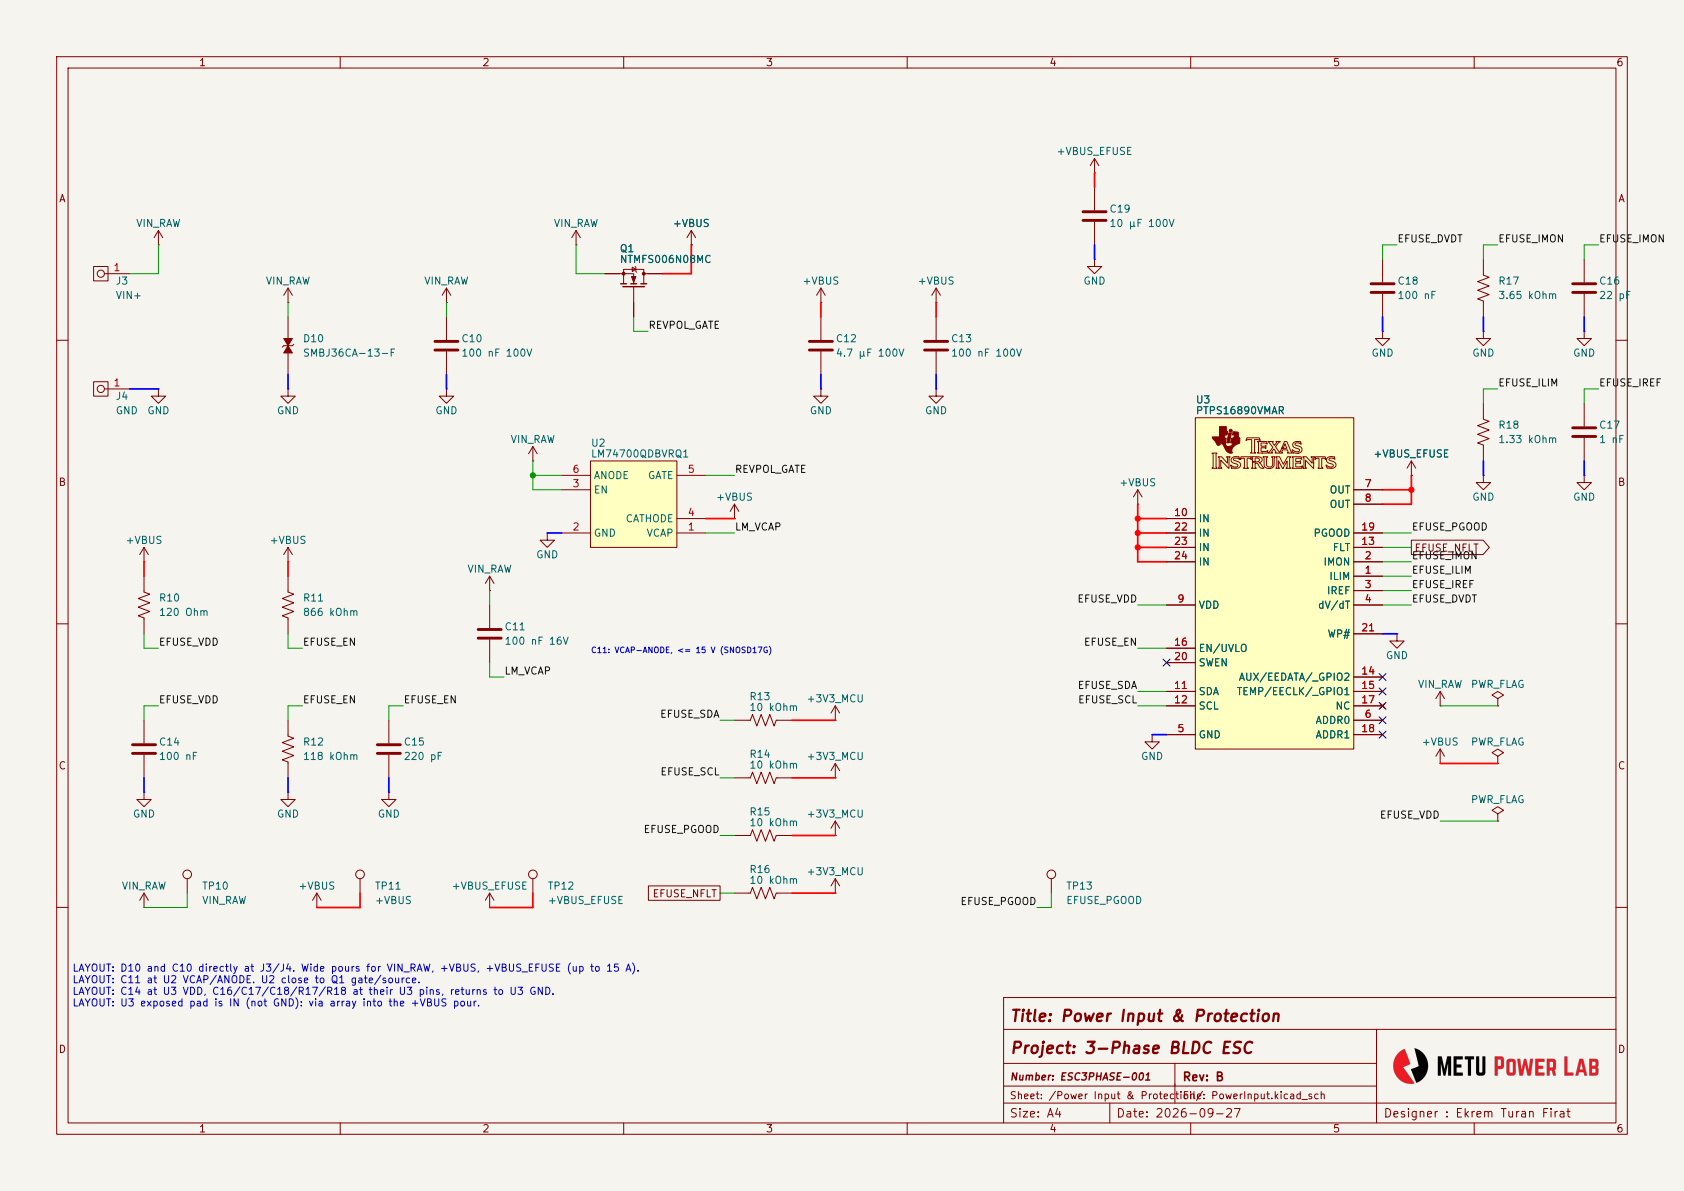
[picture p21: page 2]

Title: Power Input & Protection
Project: 3-Phase BLDC ESC

Sheet: /Power Input & Protection/ File: PowerInput.kicad_sch

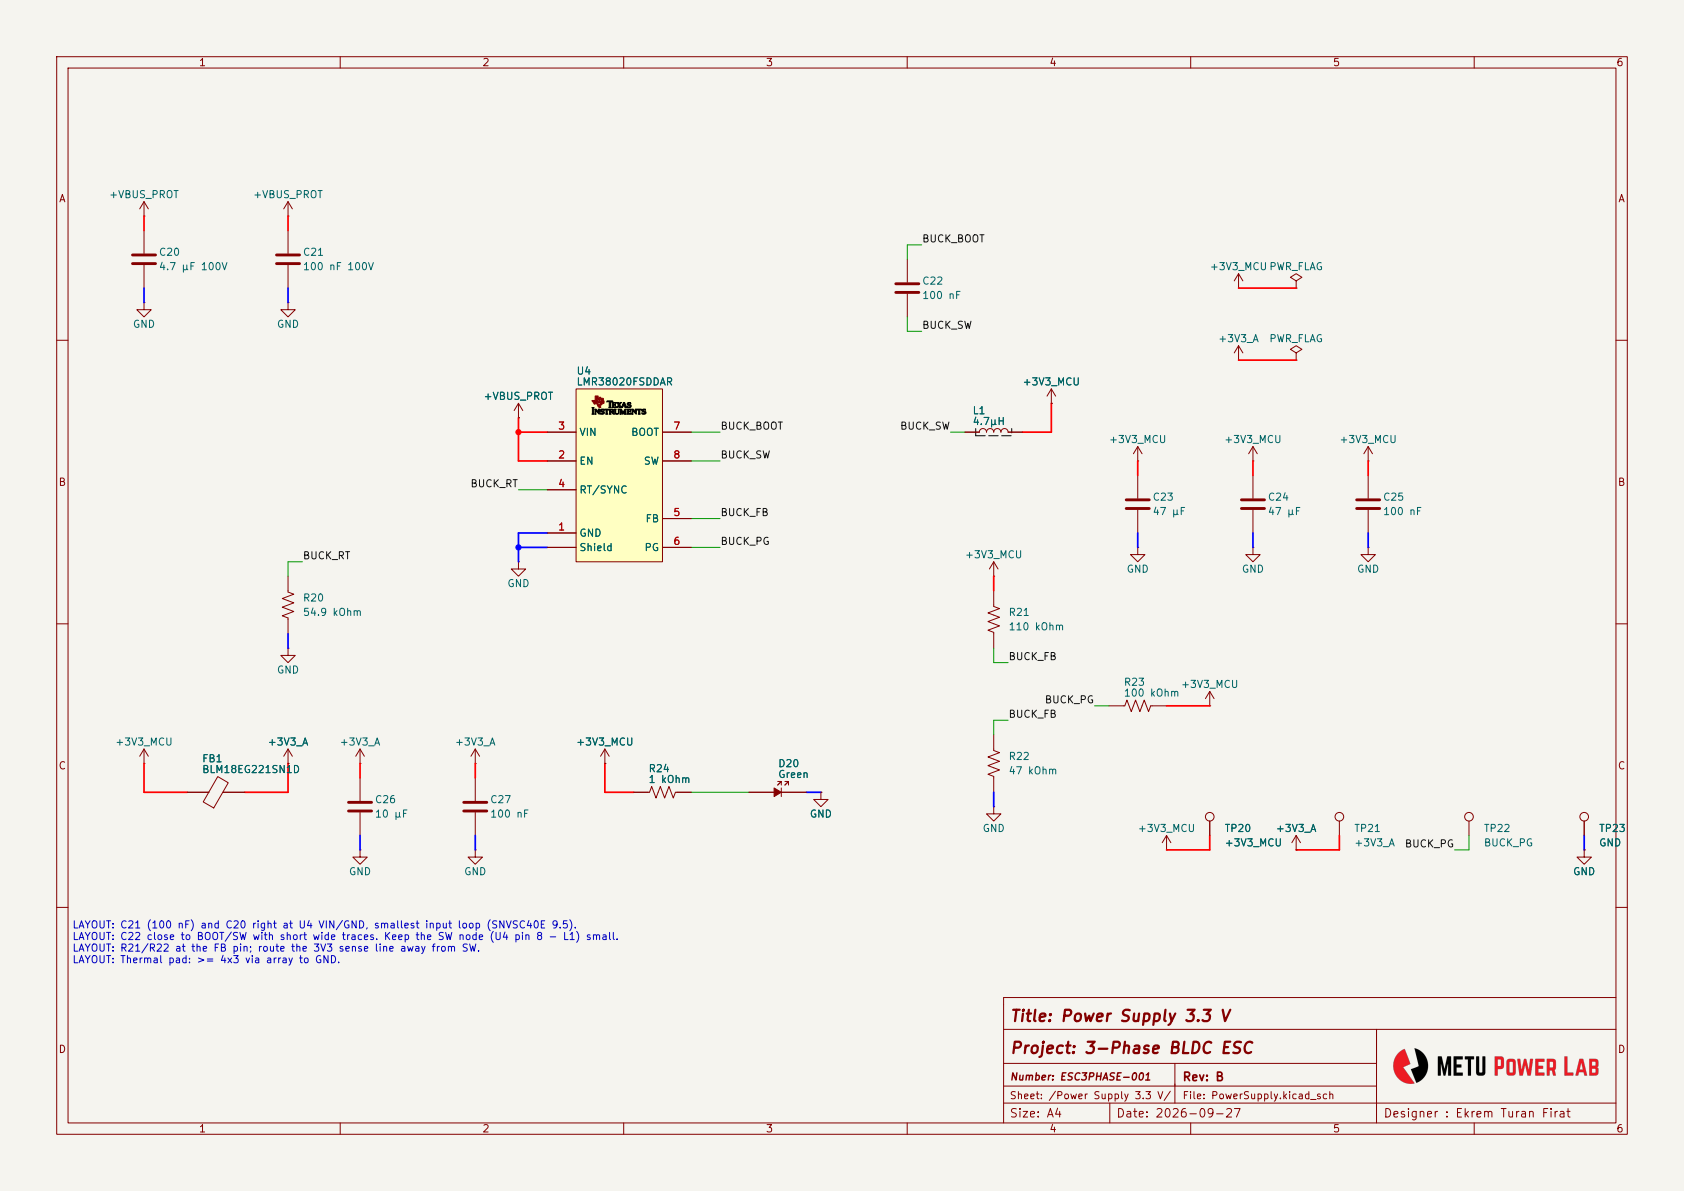
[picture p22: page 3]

Title: Power Supply 3.3 V
Project: 3-Phase BLDC ESC

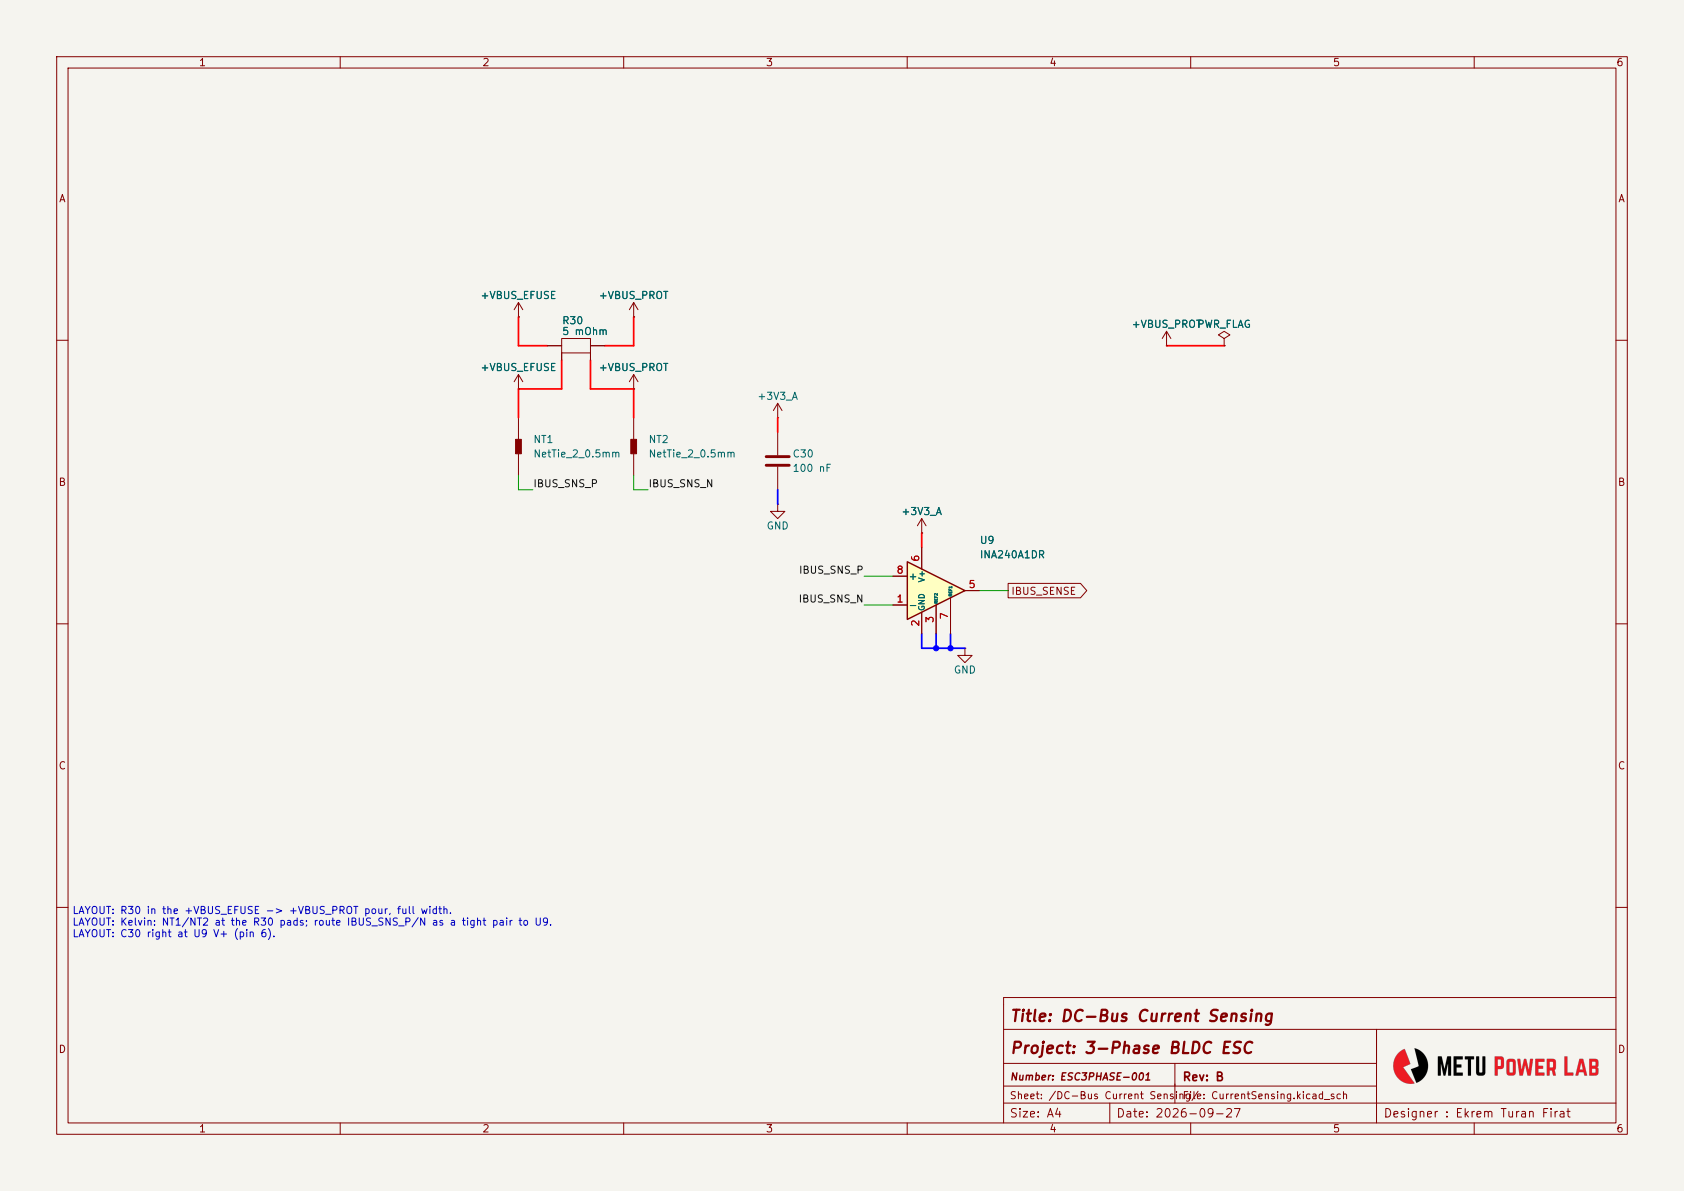
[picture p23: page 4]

LAYOUT: R30 in the +VBUS_EFUSE -> +VBUS_PROT pour, full width. LAYOUT: Kelvin: NT1/NT2 at the R30 pads; route IBUS_SNS_P/N as a tight pair to U9. LAYOUT: C30 right at U9 V+ (pin 6).

Title: DC-Bus Current Sensing
Project: 3-Phase BLDC ESC

Number: ESC3PHASE-001
Sheet: /DC-Bus Current Sensing/File: CurrentSensing.kicad_sch

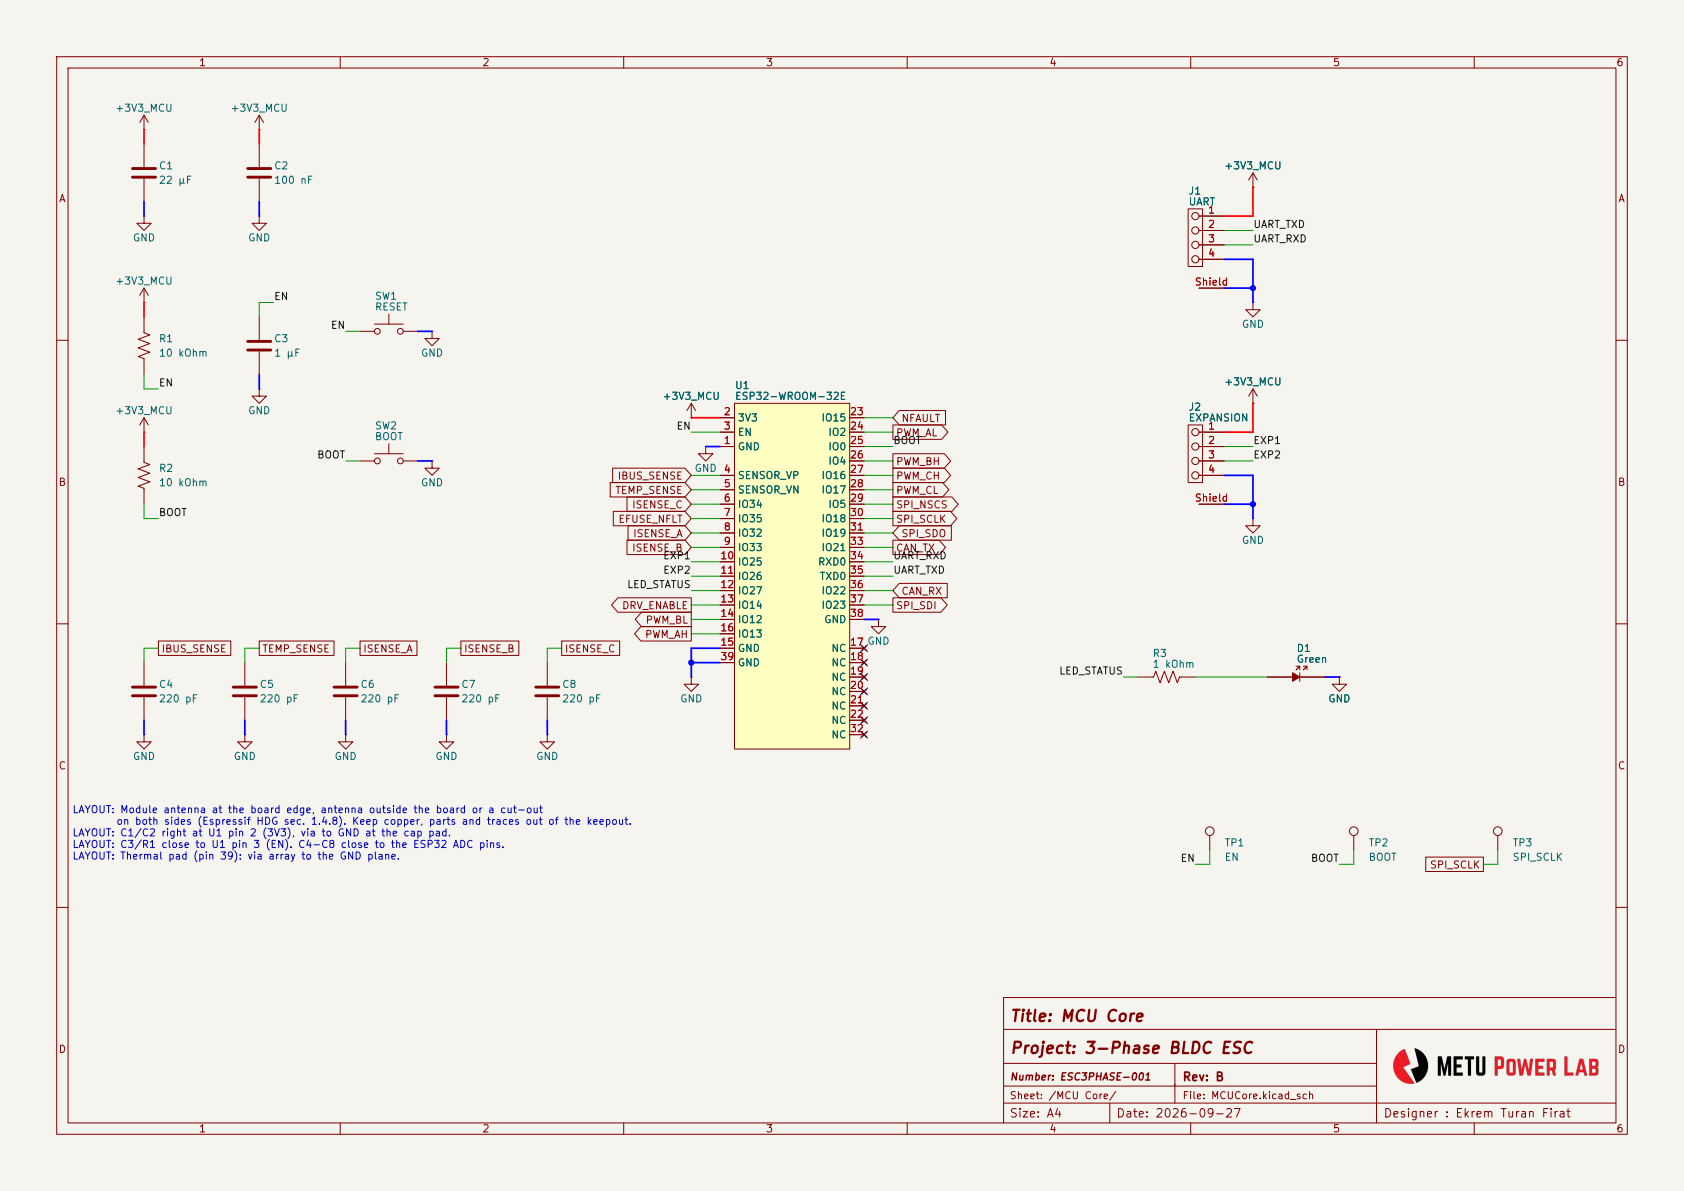
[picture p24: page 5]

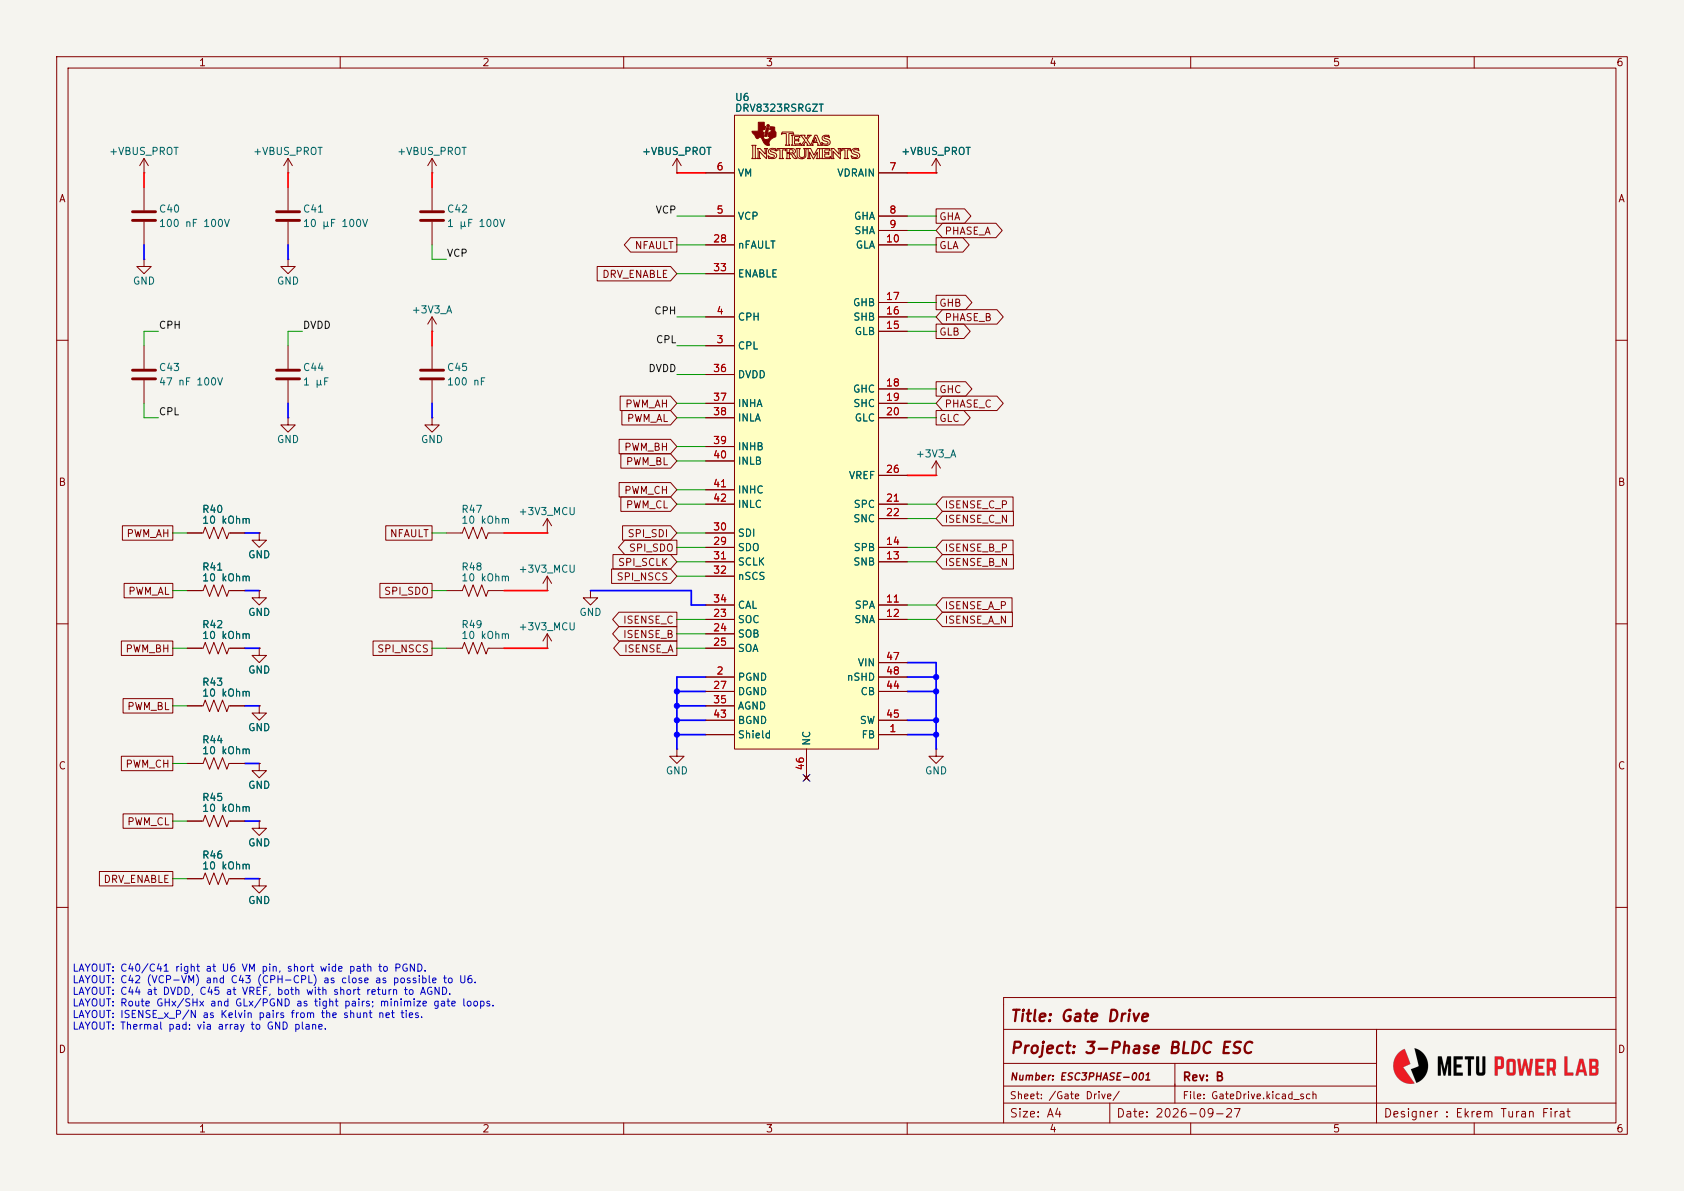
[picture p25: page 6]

LAYOUT: C40/C41 right at U6 VM pin, short wide path to PGND. LAYOUT: C42 (VCP-VM) and C43 (CPH-CPL) as close as possible to U6. LAYOUT: C44 at DVDD, C45 at VREF, both with short return to AGND. LAYOUT: Route GHx/SHx and GLx/PGND as tight pairs; minimize gate loops. LAYOUT: ISENSE_x_P/N as Kelvin pairs from the shunt net ties. LAYOUT: Thermal pad: via array to GND plane. GND

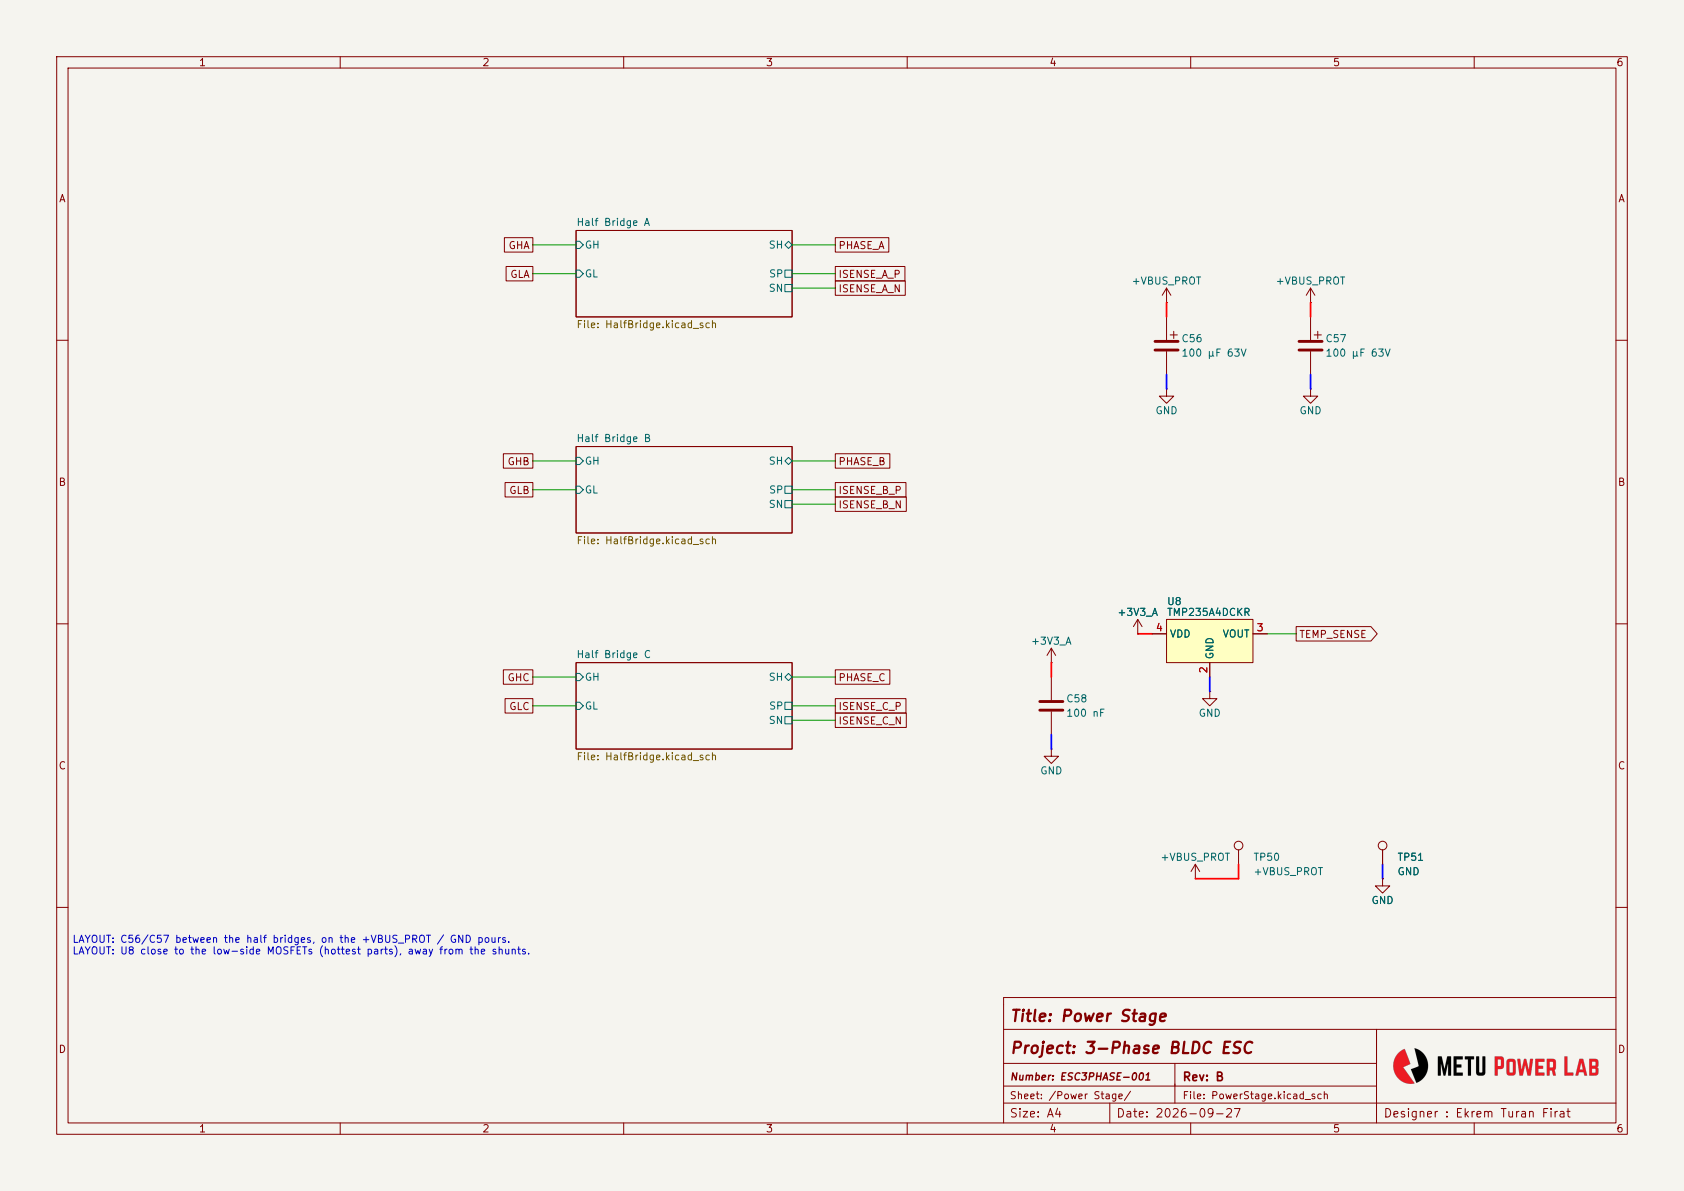
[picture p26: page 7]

Title: Power Stage
Project: 3-Phase BLDC ESC

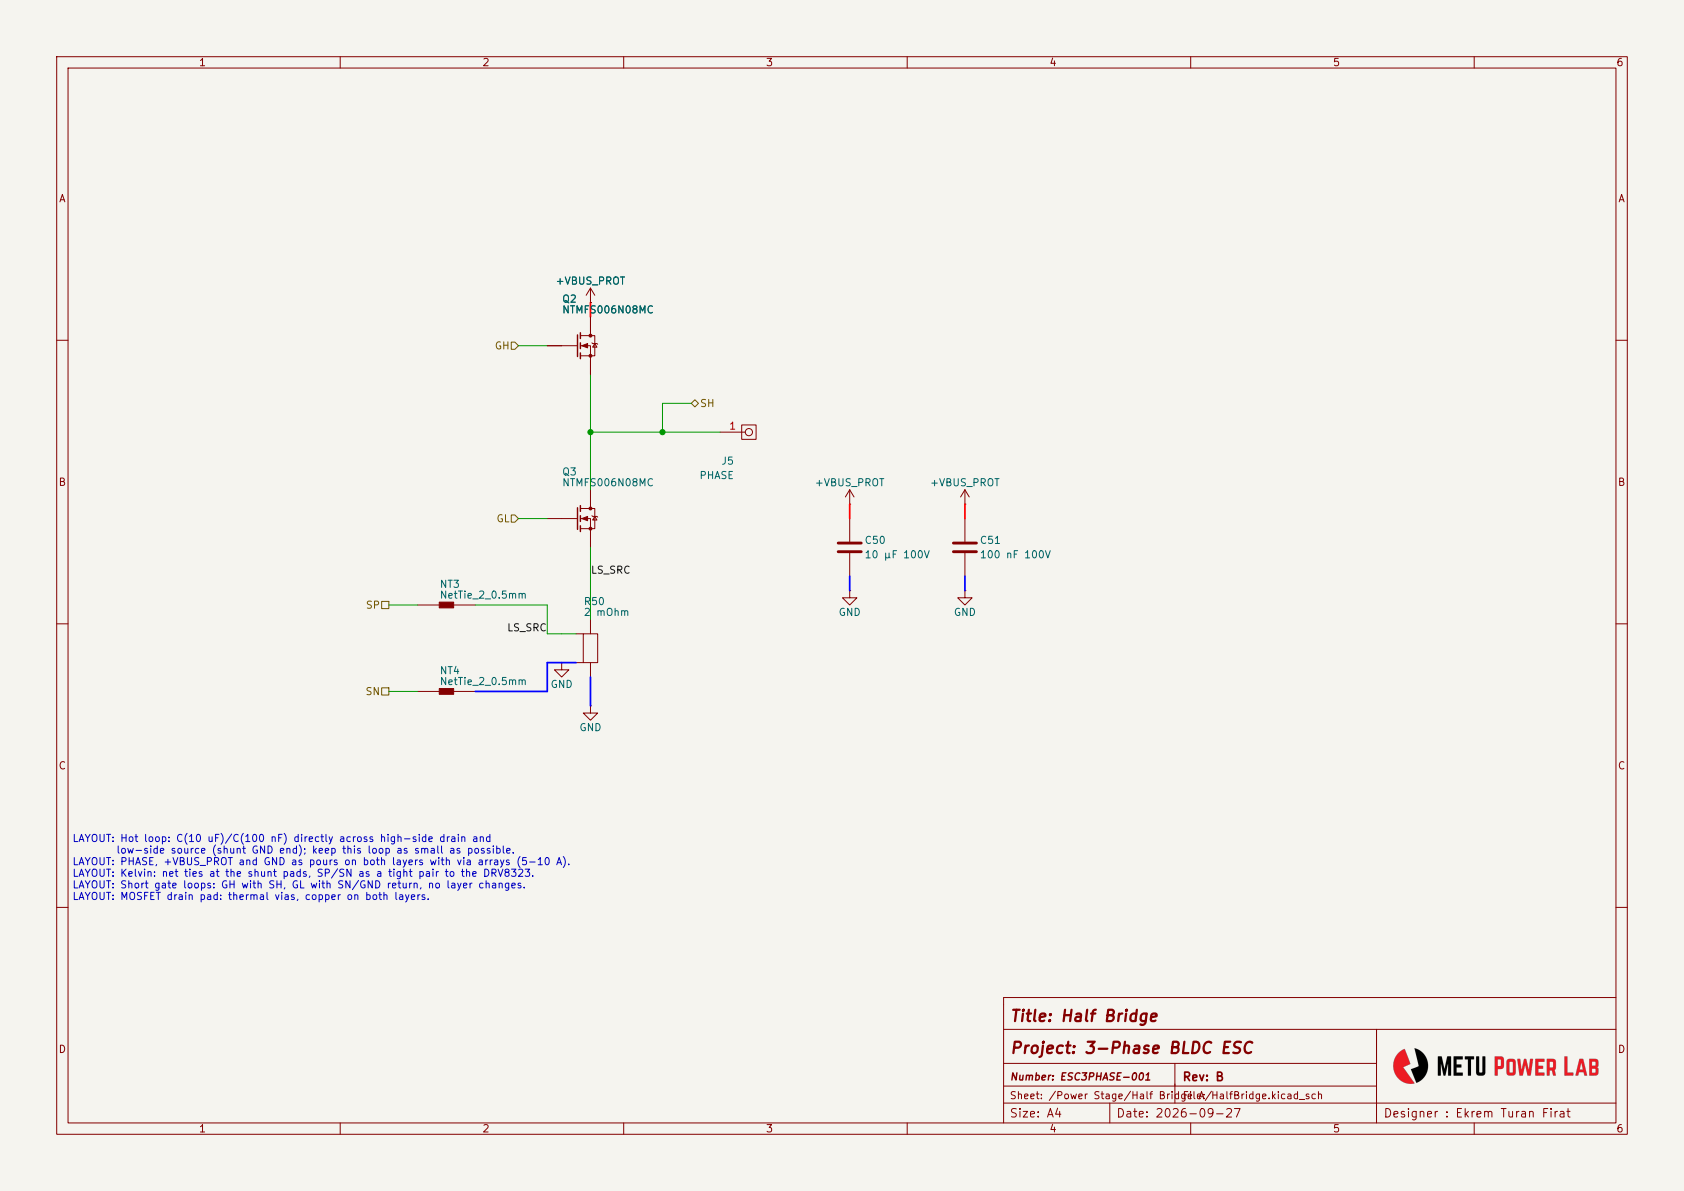
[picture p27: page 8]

LAYOUT: Hot loop: C(10 uF)/C(100 nF) directly across high-side drain and

Title: Half Bridge
Project: 3-Phase BLDC ESC

Sheet: /Power Stage/Half Bridge File: A/HalfBridge.kicad_sch

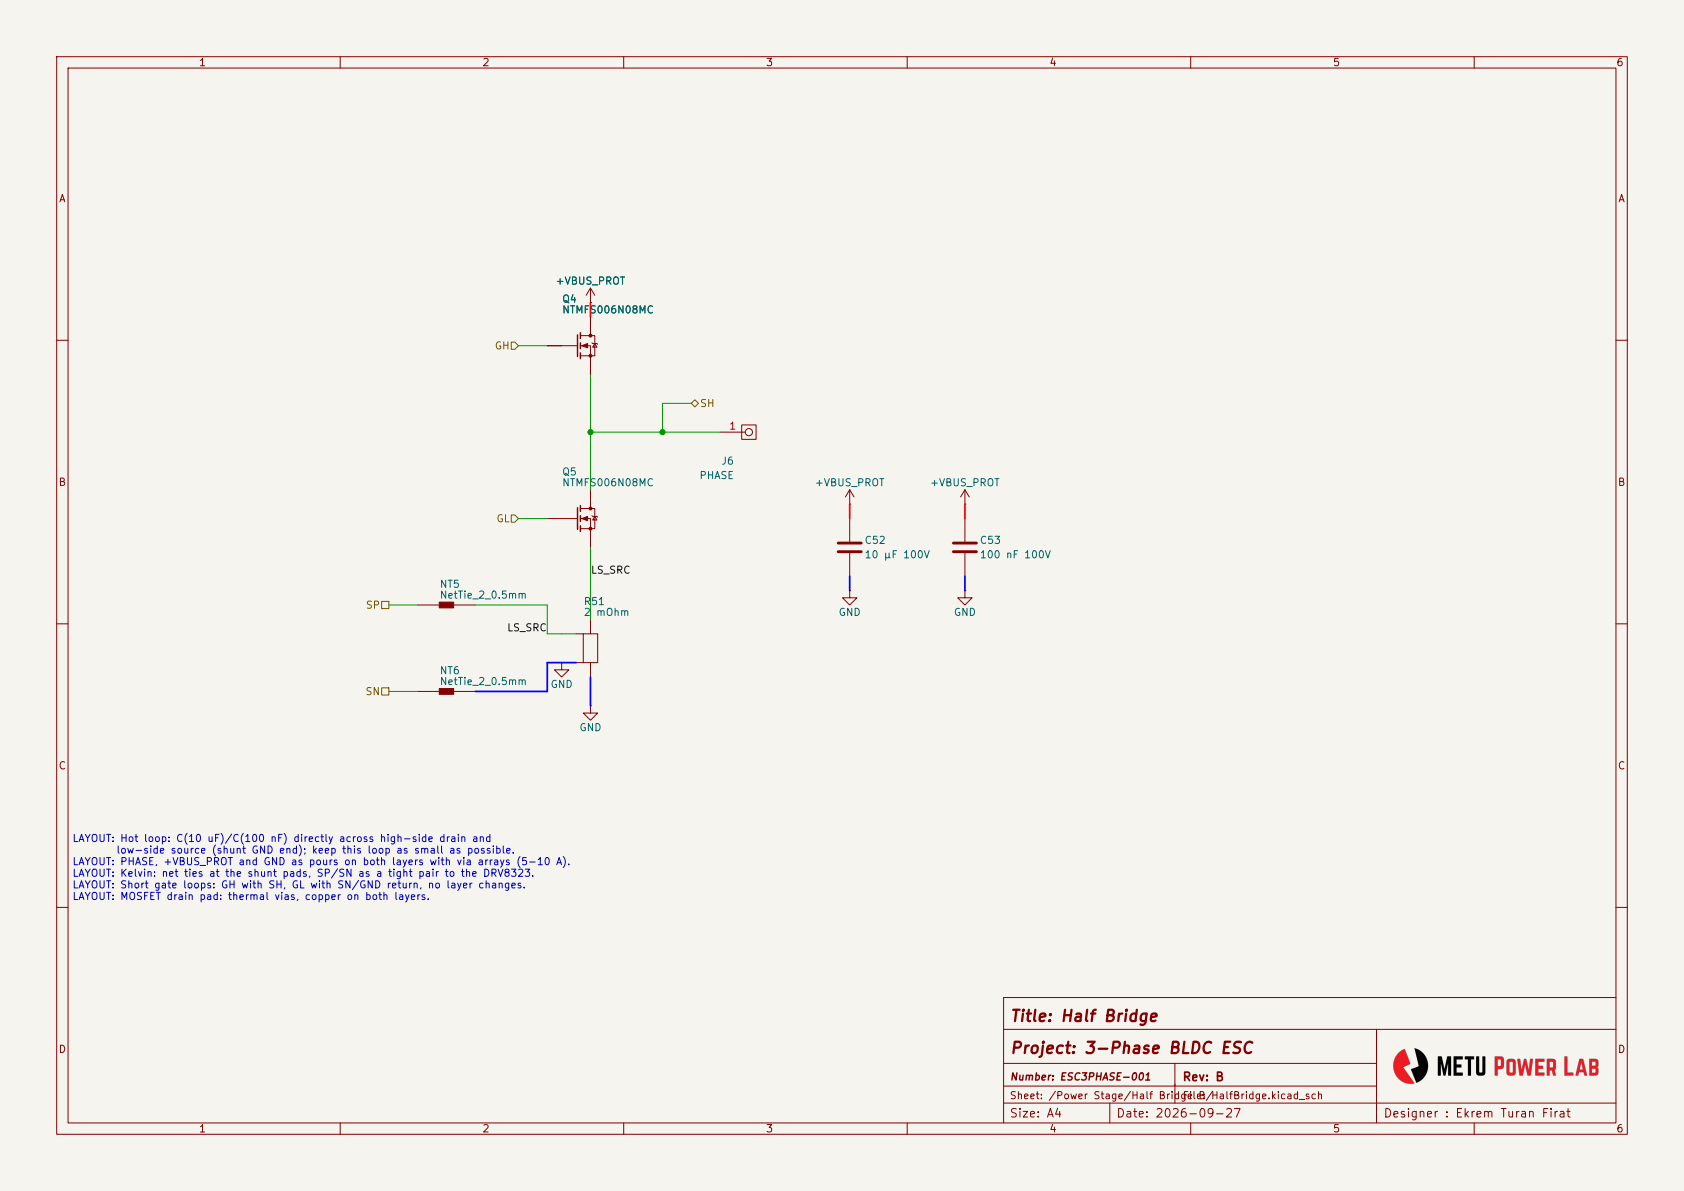
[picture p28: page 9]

LAYOUT: Hot loop: C(10 uF)/C(100 nF) directly across high-side drain and
low-side source (shunt GND end); keep this loop as small as possible. LAYOUT: PHASE, +VBUS_PROT and GND as pours on both layers with via arrays (5-10 A). LAYOUT: Kelvin: net ties at the shunt pads, SP/SN as a tight pair to the DRV8323. LAYOUT: Short gate loops: GH with SH, GL with SN/GND return, no layer changes. LAYOUT: MOSFET drain pad: thermal vias, copper on both layers.

Title: Half Bridge
Project: 3-Phase BLDC ESC

Sheet: /Power Stage/Half Bridge File: B/HalfBridge.kicad_sch

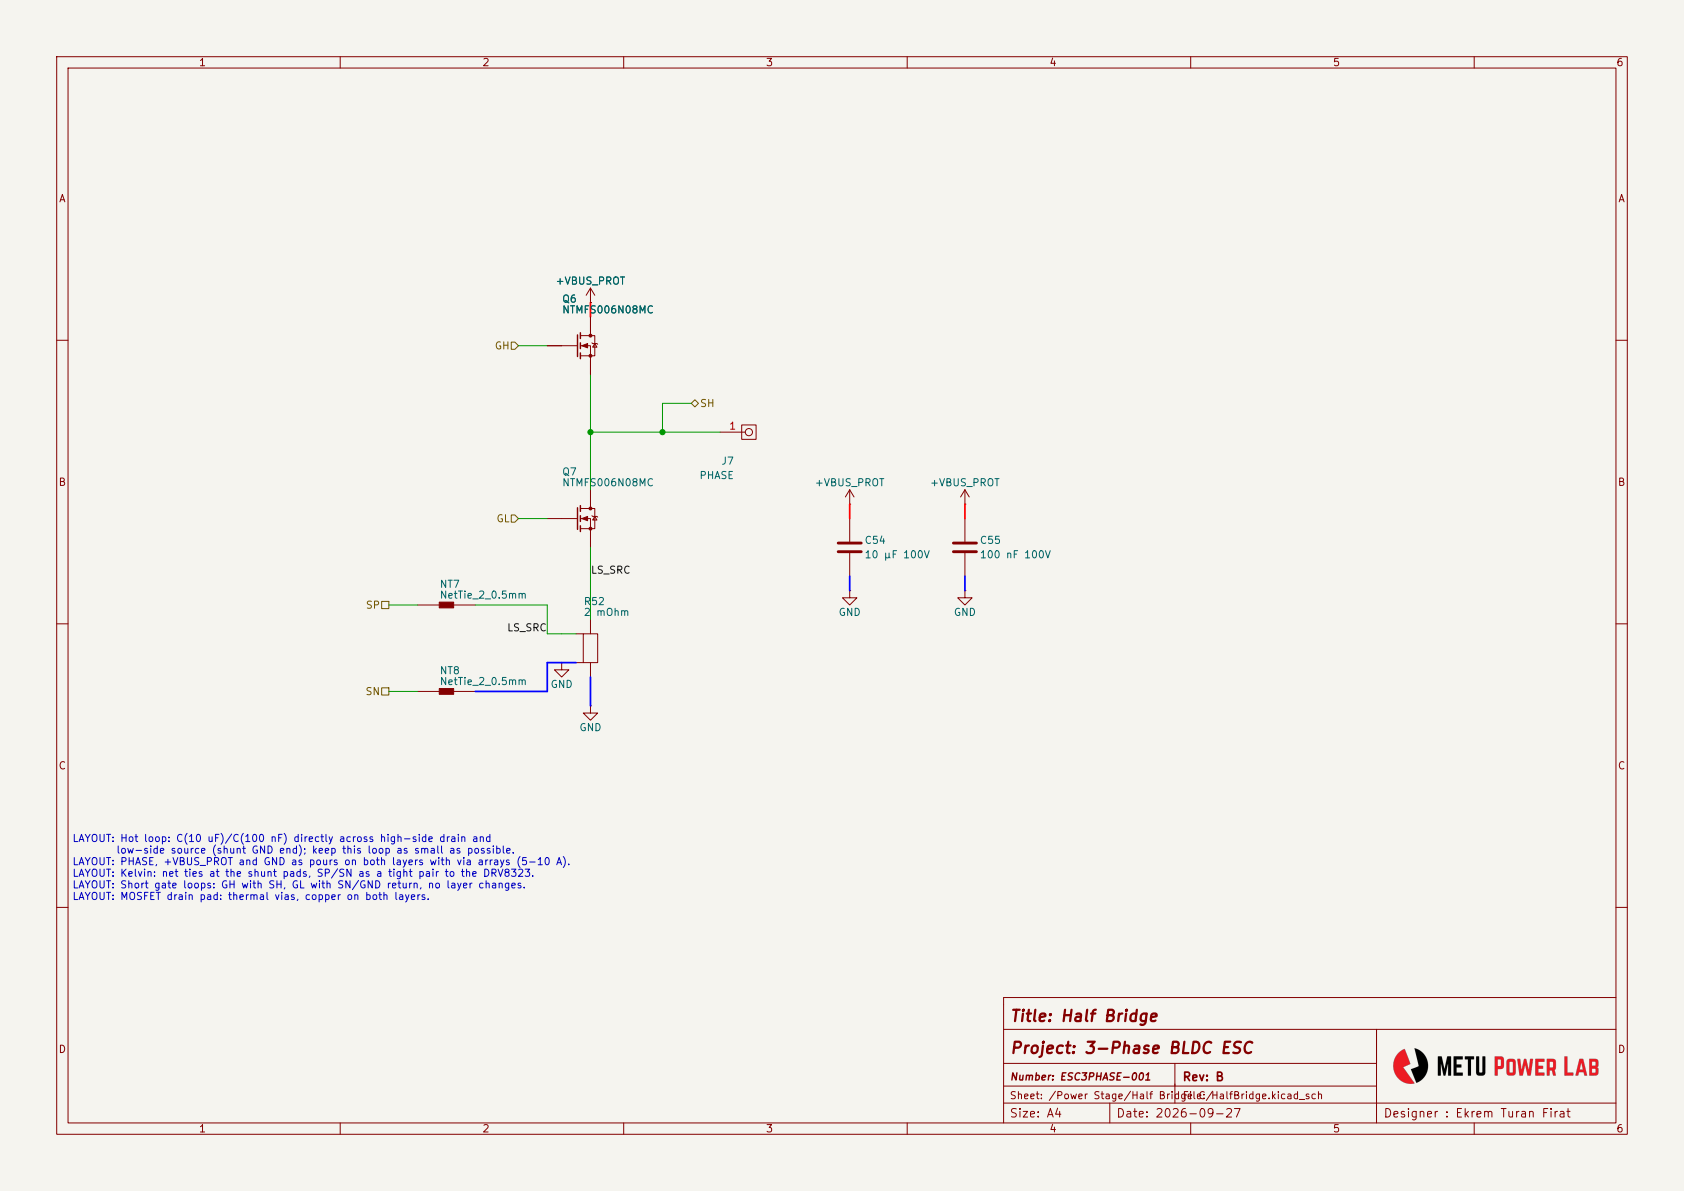
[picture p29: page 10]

LAYOUT: Hot loop: C(10 uF)/C(100 nF) directly across high-side drain and

Title: Half Bridge
Project: 3-Phase BLDC ESC

Sheet: /Power Stage/Half Bridge File: C/HalfBridge.kicad_sch

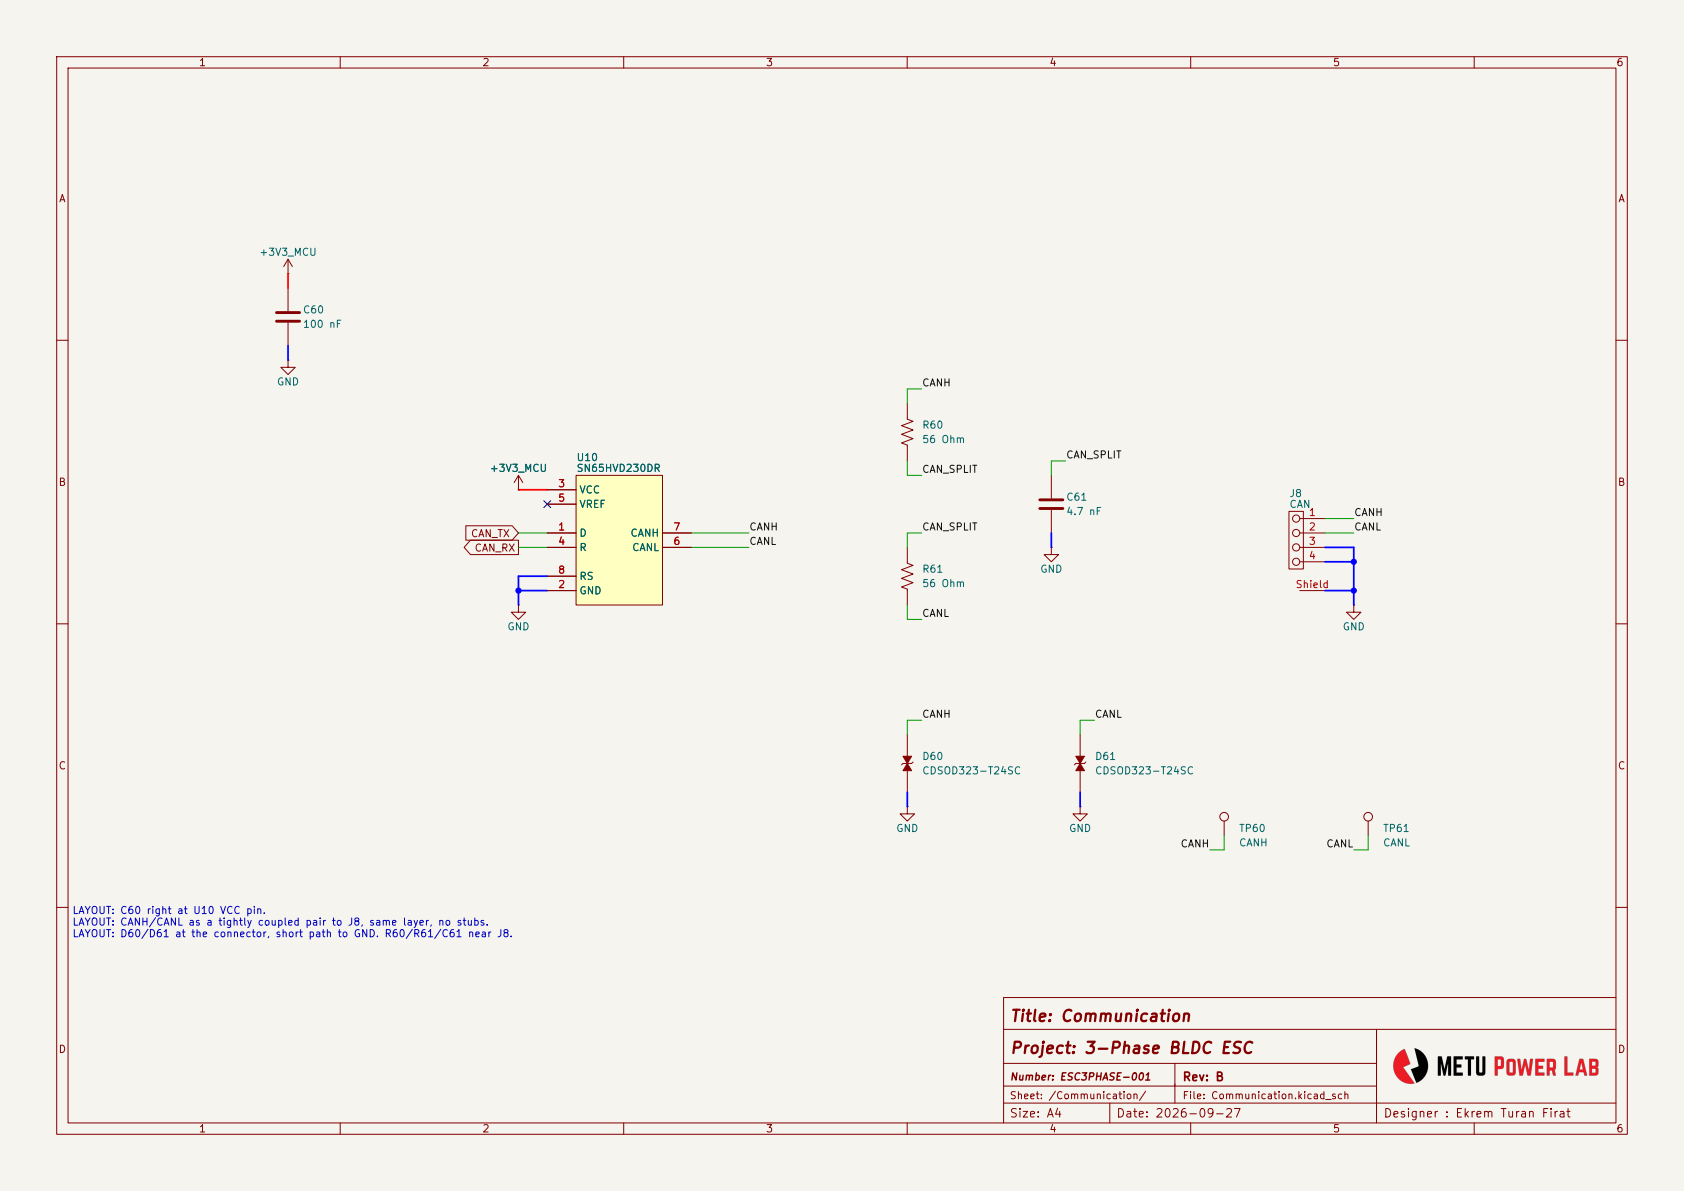
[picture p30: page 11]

LAYOUT: C60 right at U10 VCC pin. LAYOUT: CANH/CANL as a tightly coupled pair to J8, same layer, no stubs. LAYOUT: D60/D61 at the connector, short path to GND. R60/R61/C61 near J8. +3V3_MCU

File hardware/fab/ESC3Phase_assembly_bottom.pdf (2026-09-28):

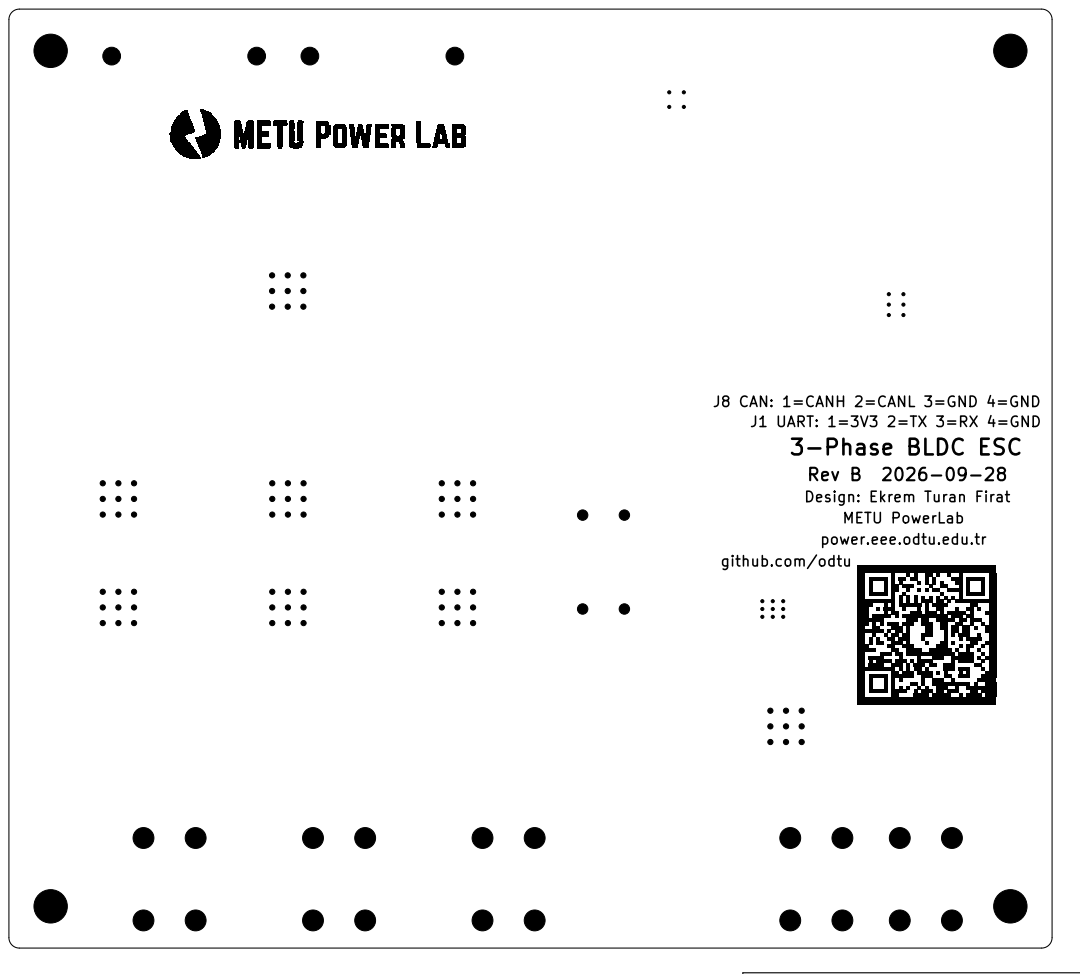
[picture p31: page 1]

J8 CAN: 1=CANH 2=CANL 3=GND 4=GND
J1 UART: 1=3V3 2=TX 3=RX 4=GND
3-Phase BLDC ESC
Rev B 2026-09-28
Number: ESC3PHASE-001 Design: Ekrem Turan Firat

METU PowerLab
power.eee.odtu.edu.tr

Title: 3-Phase BLDC ESC
Project: 3-Phase BLDC ESC

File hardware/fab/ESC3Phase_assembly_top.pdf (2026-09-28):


Title: 3-Phase BLDC ESC
Project: 3-Phase BLDC ESC

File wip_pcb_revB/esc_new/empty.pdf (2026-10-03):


Title: 3-Phase BLDC ESC (ESP32-WROOM-32E)







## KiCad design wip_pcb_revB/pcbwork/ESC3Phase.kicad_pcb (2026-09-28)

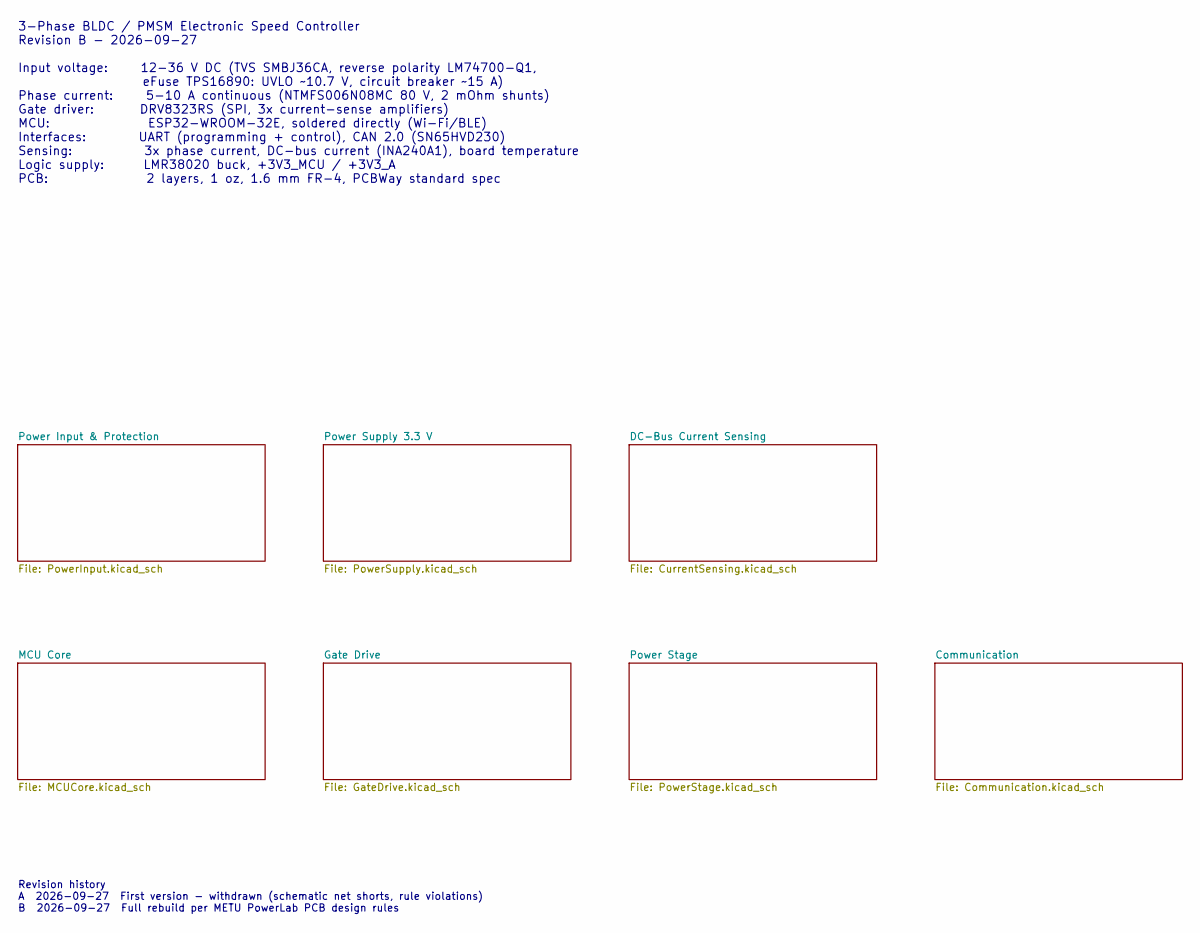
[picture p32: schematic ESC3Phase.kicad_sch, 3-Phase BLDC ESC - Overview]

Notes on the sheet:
3-Phase BLDC / PMSM Electronic Speed Controller Revision B - 2026-09-27 Input voltage: 12-36 V DC (TVS SMBJ36CA, reverse polarity LM74700-Q1, eFuse TPS16890: UVLO ~10.7 V, circuit breaker ~15 A) Phase current: 5-10 A continuous (NTMFS006N08MC 80 V, 2 mOhm shunts) Gate driver: DRV8323RS (SPI, 3x cur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
Revision history A 2026-09-27 First version - withdrawn (schematic net shorts, rule violations) B 2026-09-27 Full rebuild per METU PowerLab PCB design rules

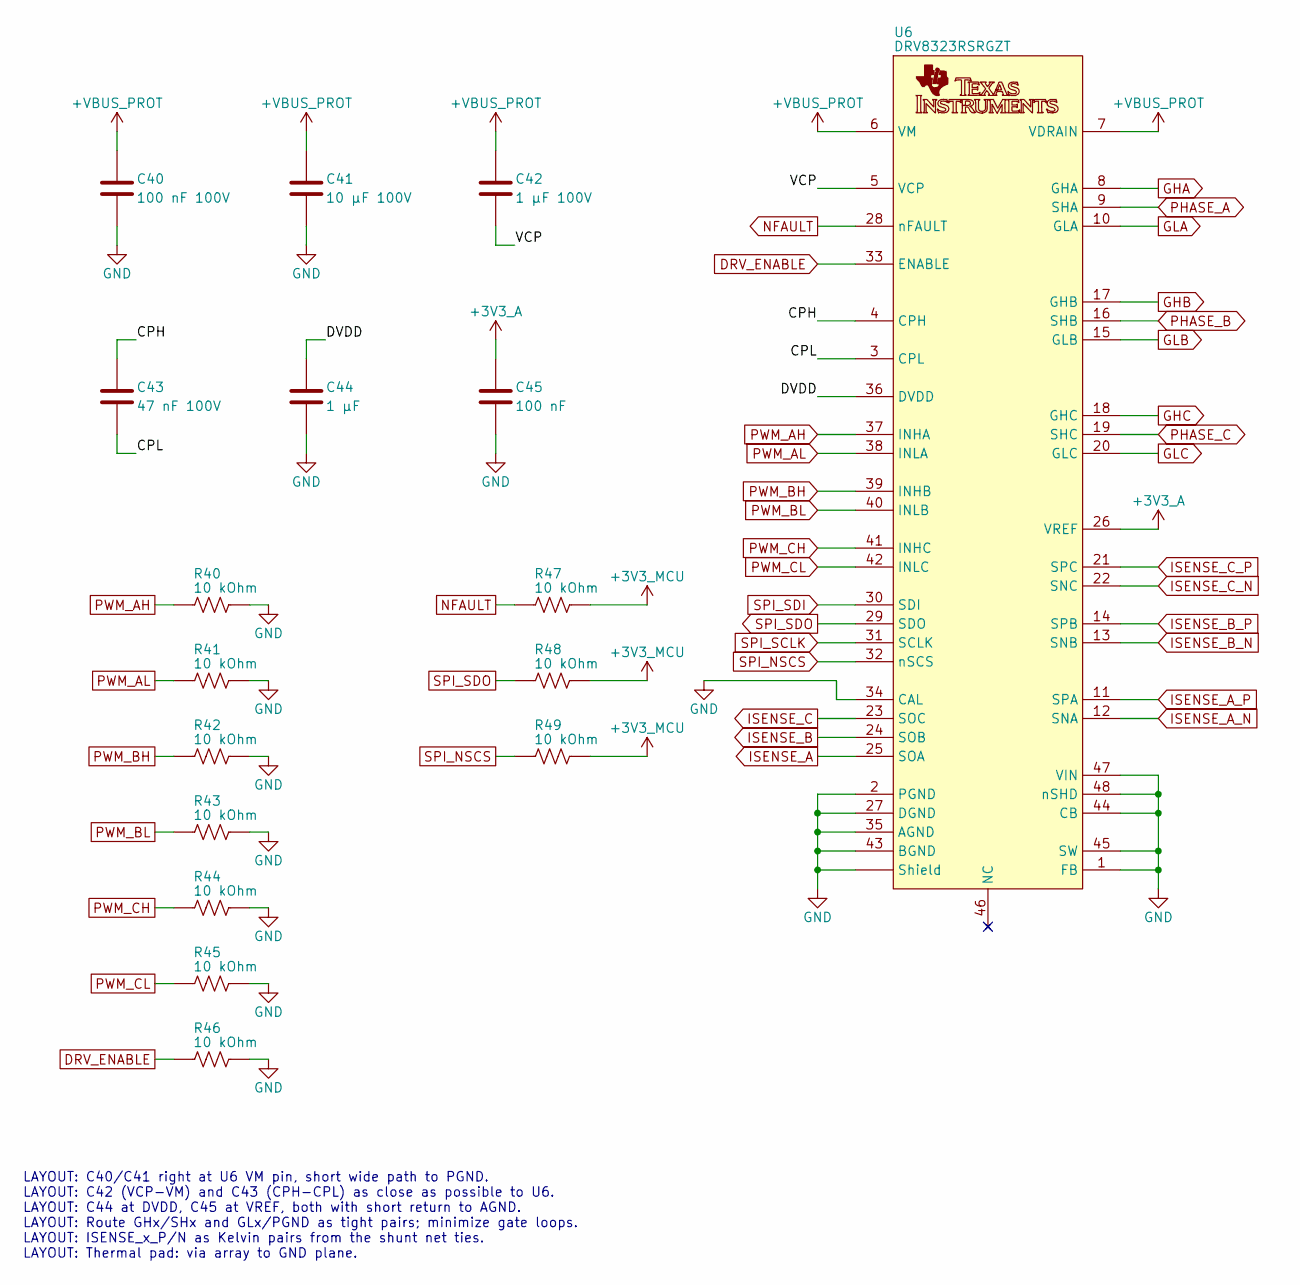
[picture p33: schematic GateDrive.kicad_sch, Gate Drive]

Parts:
C40: 100 nF 100V; 0603_Medium; Tolerance ±10%; Voltage Rating 100V; Digi-Key Number 1276-6807-1-ND
C41: 10 µF 100V; 1206_Medium; Tolerance ±10%; Voltage Rating 100V; Digi-Key Number 445-C3216X6S2A106K160ACCT-ND
C42: 1 µF 100V; 0603_Medium; Tolerance ±10%; Voltage Rating 100V; Digi-Key Number 1276-2883-1-ND
C43: 47 nF 100V; 0603_Medium; Tolerance ±10%; Voltage Rating 100V; Digi-Key Number 732-12192-1-ND
C44: 1 µF; 0603_Medium; Tolerance ±10%; Voltage Rating 100V; Digi-Key Number 1276-2883-1-ND
C45: 100 nF; 0603_Medium; Tolerance ±10%; Voltage Rating 16V; Digi-Key Number 311-1088-1-ND
R40, R41, R42, R43, R44, R45, R46, R47, R48, R49: 10 kOhm; 0603_Medium; Tolerance ±1%; Mouser Number 603-RC0603FR-0710KL
U6: DRV8323RSRGZT; 48-VQFN; Supply Voltage Rating 6V up to 60V; Digi-Key Number 296-46943-1-ND

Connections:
+3V3_A: C45.1, U6.26 (VREF); also elsewhere on the board
+3V3_MCU: R47.2, R48.2, R49.2; also elsewhere on the board
+VBUS_PROT: C40.1, C41.1, C42.1, U6.6 (VM), U6.7 (VDRAIN); also elsewhere on the board
/Gate Drive/CPH: C43.1, U6.4 (CPH)
/Gate Drive/CPL: C43.2, U6.3 (CPL)
/Gate Drive/DVDD: C44.1, U6.36 (DVDD)
/Gate Drive/VCP: C42.2, U6.5 (VCP)
DRV_ENABLE: R46.1, U6.33 (ENABLE); also elsewhere on the board
GHA: U6.8 (GHA); also elsewhere on the board
GHB: U6.17 (GHB); also elsewhere on the board
GHC: U6.18 (GHC); also elsewhere on the board
GLA: U6.10 (GLA); also elsewhere on the board
GLB: U6.15 (GLB); also elsewhere on the board
GLC: U6.20 (GLC); also elsewhere on the board
GND: C40.2, C41.2, C44.2, C45.2, R40.2, R41.2, R42.2, R43.2, R44.2, R45.2, R46.2, U6.1 (FB), U6.2 (PGND), U6.27 (DGND), U6.34 (CAL), U6.35 (AGND), U6.43 (BGND), U6.44 (CB), U6.45 (SW), U6.47 (VIN), U6.48 (nSHD), U6.Shield; also elsewhere on the board
ISENSE_A: U6.25 (SOA); also elsewhere on the board
ISENSE_A_N: U6.12 (SNA); also elsewhere on the board
ISENSE_A_P: U6.11 (SPA); also elsewhere on the board
ISENSE_B: U6.24 (SOB); also elsewhere on the board
ISENSE_B_N: U6.13 (SNB); also elsewhere on the board
ISENSE_B_P: U6.14 (SPB); also elsewhere on the board
ISENSE_C: U6.23 (SOC); also elsewhere on the board
ISENSE_C_N: U6.22 (SNC); also elsewhere on the board
ISENSE_C_P: U6.21 (SPC); also elsewhere on the board
NFAULT: R47.1, U6.28 (nFAULT); also elsewhere on the board
PHASE_A: U6.9 (SHA); also elsewhere on the board
PHASE_B: U6.16 (SHB); also elsewhere on the board
PHASE_C: U6.19 (SHC); also elsewhere on the board
PWM_AH: R40.1, U6.37 (INHA); also elsewhere on the board
PWM_AL: R41.1, U6.38 (INLA); also elsewhere on the board
PWM_BH: R42.1, U6.39 (INHB); also elsewhere on the board
PWM_BL: R43.1, U6.40 (INLB); also elsewhere on the board
PWM_CH: R44.1, U6.41 (INHC); also elsewhere on the board
PWM_CL: R45.1, U6.42 (INLC); also elsewhere on the board
SPI_NSCS: R49.1, U6.32 (nSCS); also elsewhere on the board
SPI_SCLK: U6.31 (SCLK); also elsewhere on the board
SPI_SDI: U6.30 (SDI); also elsewhere on the board
SPI_SDO: R48.1, U6.29 (SDO); also elsewhere on the board

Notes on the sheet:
LAYOUT: C40/C41 right at U6 VM pin, short wide path to PGND. LAYOUT: C42 (VCP-VM) and C43 (CPH-CPL) as close as possible to U6. LAYOUT: C44 at DVDD, C45 at VREF, both with short return to AGND. LAYOUT: Route GHx/SHx and GLx/PGND as tight pairs; minimize gate loops. LAYOUT: ISENSE_x_P/N as Kelvin pa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

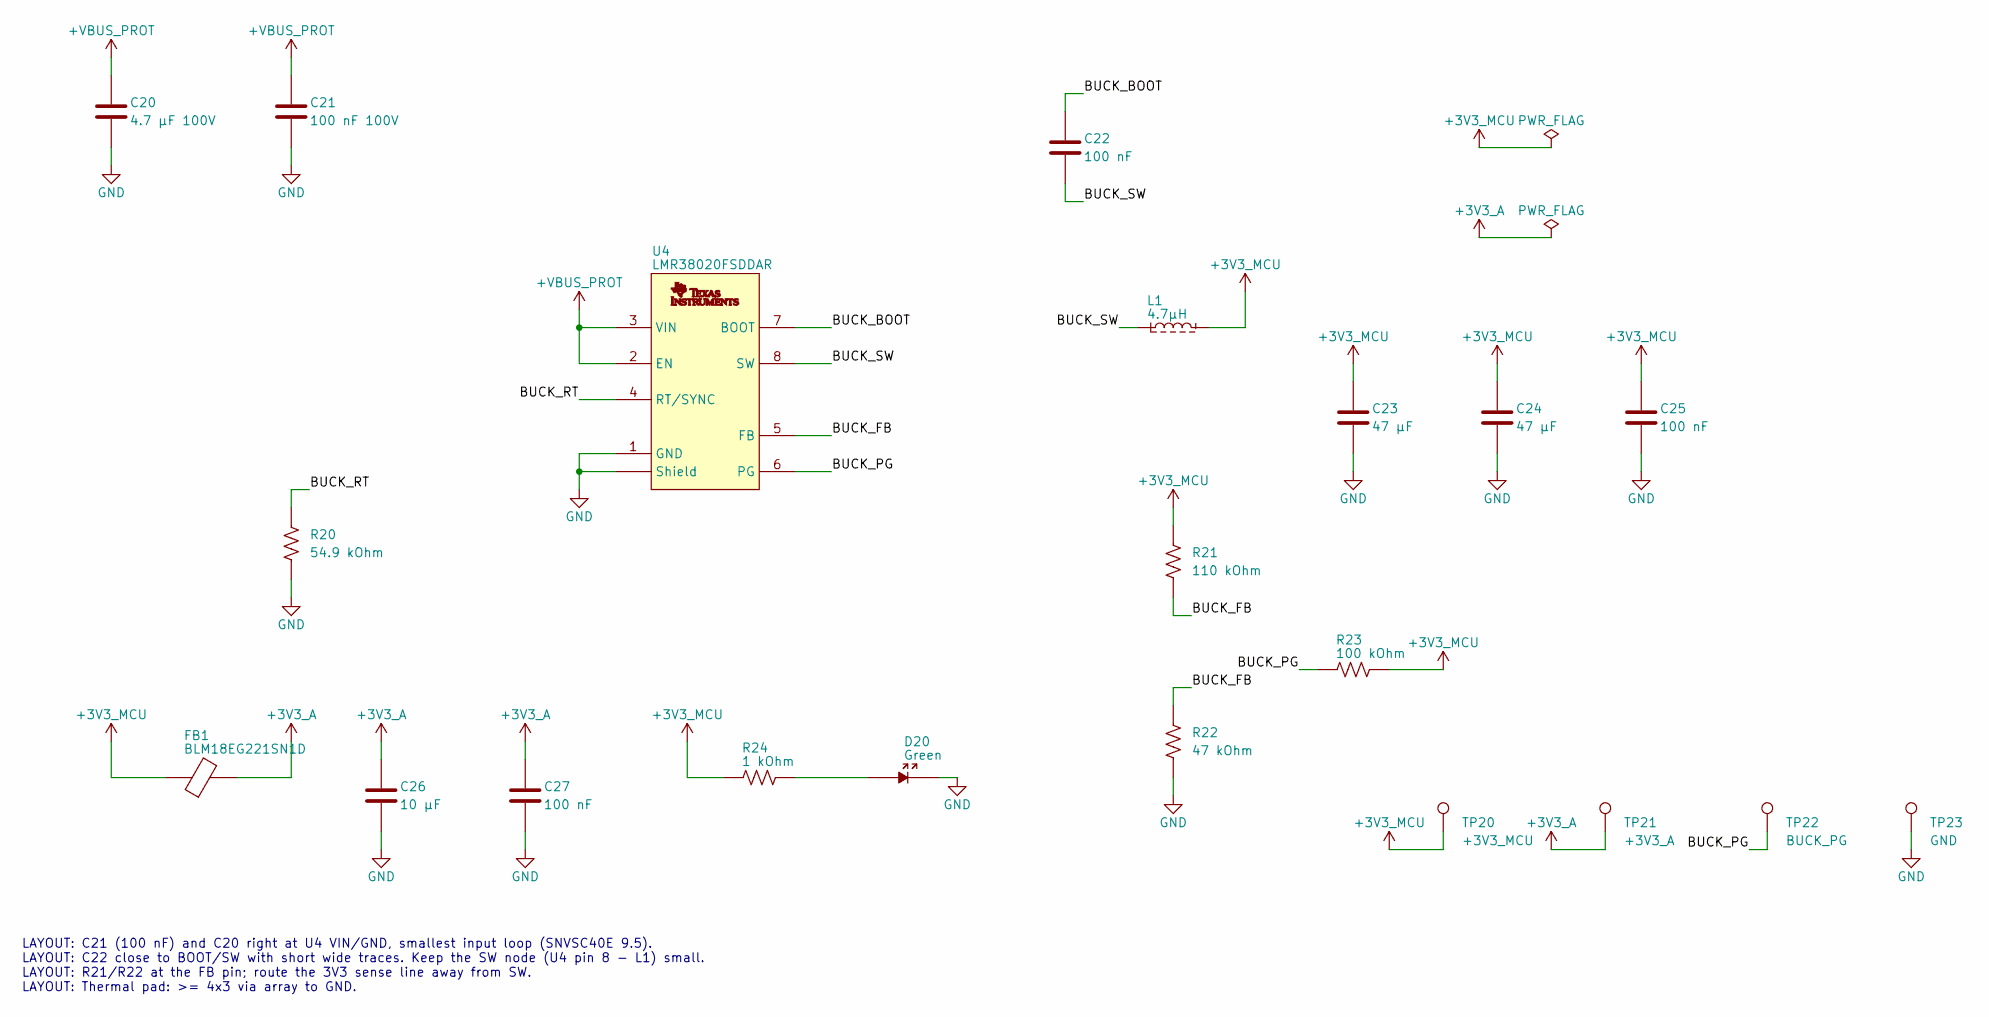
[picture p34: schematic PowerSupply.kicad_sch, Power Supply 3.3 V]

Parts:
C20: 4.7 µF 100V; 1210_Medium; Tolerance ±20%; Voltage Rating 100V; Digi-Key Number 1276-CL32Y475MCIVPNECT-ND
C21: 100 nF 100V; 0603_Medium; Tolerance ±10%; Voltage Rating 100V; Digi-Key Number 1276-6807-1-ND
C22, C25, C27: 100 nF; 0603_Medium; Tolerance ±10%; Voltage Rating 16V; Digi-Key Number 311-1088-1-ND
C23, C24: 47 µF; 1210_Medium; Tolerance ±20%; Voltage Rating 25V; Digi-Key Number 587-6156-1-ND
C26: 10 µF; 0603_Medium; Tolerance ±20%; Voltage Rating 10V; Digi-Key Number 1276-1871-1-ND
D20: Green; 0603_Medium; Forward Voltage 3.2V; Current Rating 20mA; Digi-Key Number 732-4971-1-ND
FB1: BLM18EG221SN1D; 0603_Medium; Current Rating 2A; Digi-Key Number 490-3992-1-ND
L1: 4.7µH; 6x5_7mm; Tolerance ±20%; Current Rating 8.1A; Digi-Key Number 283-EXLA1V0505-4R7-RCT-ND
R20: 54.9 kOhm; 0603_Medium; Tolerance ±1%; Mouser Number 708-RMCF0603FT54K9
R21: 110 kOhm; 0603_Medium; Tolerance ±1%; Mouser Number 708-RMCF0603FT110K
R22: 47 kOhm; 0603_Medium; Tolerance ±1%; Mouser Number 708-RMCF0603FT47K0
R23: 100 kOhm; 0603_Medium; Tolerance ±1%; Mouser Number 708-RMCF0603FT100K
R24: 1 kOhm; 0603_Medium; Tolerance ±1%; Mouser Number 708-RMCF0603FT1K00
TP20: +3V3_MCU; Pad_D1.5mm
TP21: +3V3_A; Pad_D1.5mm
TP22: BUCK_PG; Pad_D1.5mm
TP23: GND; Pad_D1.5mm
U4: LMR38020FSDDAR; 8-SOICPower; Voltage Input Rating 4.2V up to 80V; Voltage Output Rating 1V up to 75V; Digi-Key Number 296-LMR38020FSDDARCT-ND

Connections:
+3V3_A: C26.1, C27.1, FB1.2, TP21.1; also elsewhere on the board
+3V3_MCU: C23.1, C24.1, C25.1, FB1.1, L1.2, R21.1, R23.2, R24.1, TP20.1; also elsewhere on the board
+VBUS_PROT: C20.1, C21.1, U4.2 (EN), U4.3 (VIN); also elsewhere on the board
/Power Supply 3.3 V/BUCK_BOOT: C22.1, U4.7 (BOOT)
/Power Supply 3.3 V/BUCK_FB: R21.2, R22.1, U4.5 (FB)
/Power Supply 3.3 V/BUCK_PG: R23.1, TP22.1, U4.6 (PG)
/Power Supply 3.3 V/BUCK_RT: R20.1, U4.4 (RT/SYNC)
/Power Supply 3.3 V/BUCK_SW: C22.2, L1.1, U4.8 (SW)
GND: C20.2, C21.2, C23.2, C24.2, C25.2, C26.2, C27.2, D20.2, R20.2, R22.2, TP23.1, U4.1 (GND), U4.Shield; also elsewhere on the board
unnamed: D20.1, R24.2

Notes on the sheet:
LAYOUT: C21 (100 nF) and C20 right at U4 VIN/GND, smallest input loop (SNVSC40E 9.5). LAYOUT: C22 close to BOOT/SW with short wide traces. Keep the SW node (U4 pin 8 - L1) small. LAYOUT: R21/R22 at the FB pin; route the 3V3 sense line away from SW. LAYOUT: Thermal pad: >= 4x3 via array to GND.

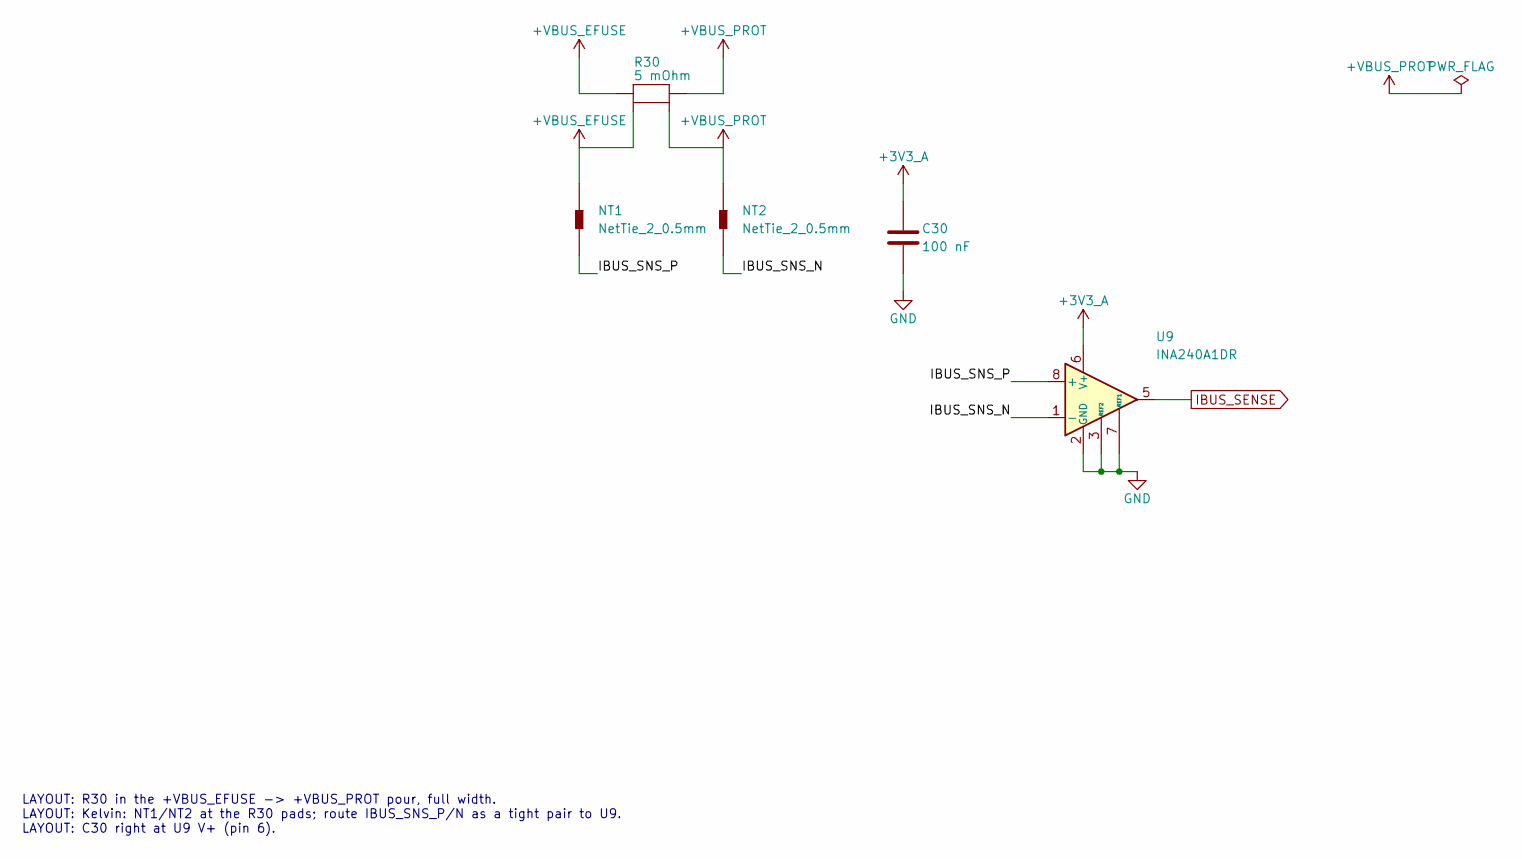
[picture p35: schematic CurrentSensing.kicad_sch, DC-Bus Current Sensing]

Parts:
C30: 100 nF; 0603_Medium; Tolerance ±10%; Voltage Rating 16V; Digi-Key Number 311-1088-1-ND
NT1, NT2: NetTie_2_0.5mm
R30: 5 mOhm; 2010; Tolerance ±1%; Digi-Key Number 4423-VMP-R005-1.0-UCT-ND
U9: INA240A1DR; 8-SOIC; Voltage Range 2.7V up to 5.5V; Digi-Key Number 296-51172-1-ND

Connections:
+3V3_A: C30.1, U9.6 (V+); also elsewhere on the board
+VBUS_EFUSE: NT1.1, R30.1; also elsewhere on the board
+VBUS_PROT: NT2.1, R30.2; also elsewhere on the board
/DC-Bus Current Sensing/IBUS_SNS_N: NT2.2, U9.1 (-)
/DC-Bus Current Sensing/IBUS_SNS_P: NT1.2, U9.8 (+)
GND: C30.2, U9.2 (GND), U9.3 (REF2), U9.4 (GND), U9.7 (REF1); also elsewhere on the board
IBUS_SENSE: U9.5; also elsewhere on the board

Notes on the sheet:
LAYOUT: R30 in the +VBUS_EFUSE -> +VBUS_PROT pour, full width. LAYOUT: Kelvin: NT1/NT2 at the R30 pads; route IBUS_SNS_P/N as a tight pair to U9. LAYOUT: C30 right at U9 V+ (pin 6).

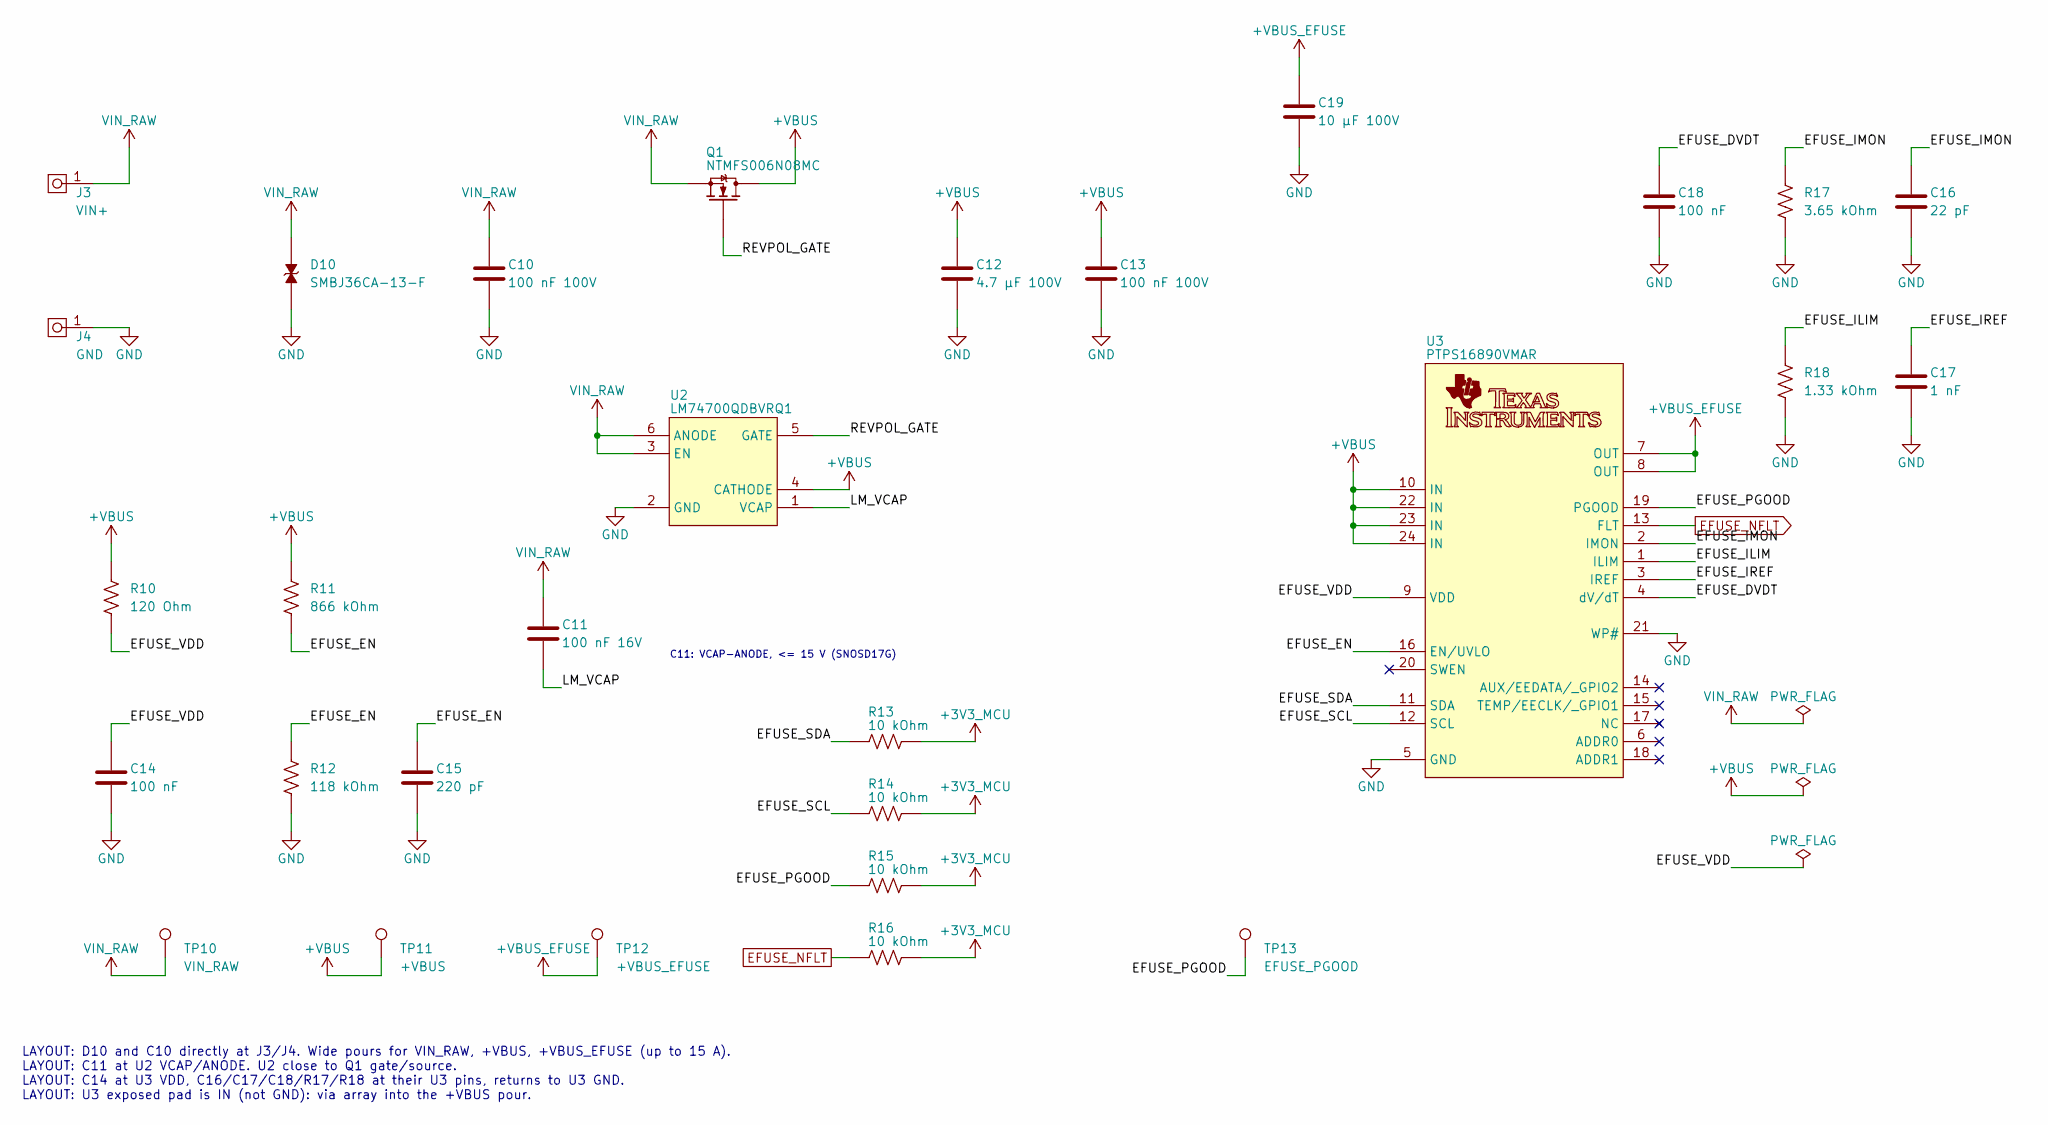
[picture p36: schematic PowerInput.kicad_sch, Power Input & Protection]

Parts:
C10, C13: 100 nF 100V; 0603_Medium; Tolerance ±10%; Voltage Rating 100V; Digi-Key Number 1276-6807-1-ND
C11: 100 nF 16V; 0603_Medium; Tolerance ±10%; Voltage Rating 16V; Digi-Key Number 311-1088-1-ND
C12: 4.7 µF 100V; 1210_Medium; Tolerance ±20%; Voltage Rating 100V; Digi-Key Number 1276-CL32Y475MCIVPNECT-ND
C14: 100 nF; 0603_Medium; Tolerance ±10%; Voltage Rating 100V; Digi-Key Number 1276-6807-1-ND
C15: 220 pF; 0603_Medium; Tolerance ±5%; Voltage Rating 50V; Digi-Key Number 1276-1985-1-ND
C16: 22 pF; 0603_Medium; Tolerance ±50%; Voltage Rating 50V; Digi-Key Number 1276-2228-1-ND
C17: 1 nF; 0603_Medium; Tolerance ±5%; Voltage Rating 100V; Digi-Key Number 490-4772-1-ND
C18: 100 nF; 0603_Medium; Tolerance ±10%; Voltage Rating 16V; Digi-Key Number 311-1088-1-ND
C19: 10 µF 100V; 1206_Medium; Tolerance ±10%; Voltage Rating 100V; Digi-Key Number 445-C3216X6S2A106K160ACCT-ND
D10: SMBJ36CA-13-F; DO-214AA; Breakdown Voltage 40V; Clamping Voltage 58.1V; Digi-Key Number SMBJ36CA-FDICT-ND
J3: VIN+; 7770; Current Rating 13A; Mouser Number 534-7770
J4: GND; 7770; Current Rating 13A; Mouser Number 534-7770
Q1: NTMFS006N08MC; 8-PowerTDFN(5x6mm); Digi-Key Number 488-NTMFS006N08MCCT-ND
R10: 120 Ohm; 0603_Medium; Tolerance ±1%; Mouser Number 708-RMCF0603FT120R
R11: 866 kOhm; 0603_Medium; Tolerance ±1%; Mouser Number 708-RMCF0603FT866K
R12: 118 kOhm; 0603_Medium; Tolerance ±1%; Mouser Number 708-RMCF0603FT118K
R13, R14, R15, R16: 10 kOhm; 0603_Medium; Tolerance ±1%; Mouser Number 603-RC0603FR-0710KL
R17: 3.65 kOhm; 0603_Medium; Tolerance ±1%; Mouser Number 708-RMCF0603FT3K65
R18: 1.33 kOhm; 0603_Medium; Tolerance ±1%; Mouser Number 708-RMCF0603FT1K33
TP10: VIN_RAW; Pad_D1.5mm
TP11: +VBUS; Pad_D1.5mm
TP12: +VBUS_EFUSE; Pad_D1.5mm
TP13: EFUSE_PGOOD; Pad_D1.5mm
U2: LM74700QDBVRQ1; SOT-23-6_DBV; Voltage Rating 3.2V up to 65V; Digi-Key Number 296-LM74700QDBVRQ1CT-ND
U3: PTPS16890VMAR; 23-LQFN-CLIP_(VMA)

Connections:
+3V3_MCU: R13.2, R14.2, R15.2, R16.2; also elsewhere on the board
+VBUS: C12.1, C13.1, Q1.3 (D), R10.1, R11.1, TP11.1, U2.4 (CATHODE), U3.10 (IN), U3.22 (IN), U3.23 (IN), U3.24 (IN)
+VBUS_EFUSE: C19.1, TP12.1, U3.7 (OUT), U3.8 (OUT); also elsewhere on the board
/Power Input & Protection/EFUSE_DVDT: C18.1, U3.4 (dV/dT)
/Power Input & Protection/EFUSE_EN: C15.1, R11.2, R12.1, U3.16 (EN/UVLO)
/Power Input & Protection/EFUSE_ILIM: R18.1, U3.1 (ILIM)
/Power Input & Protection/EFUSE_IMON: C16.1, R17.1, U3.2 (IMON)
/Power Input & Protection/EFUSE_IREF: C17.1, U3.3 (IREF)
/Power Input & Protection/EFUSE_PGOOD: R15.1, TP13.1, U3.19 (PGOOD)
/Power Input & Protection/EFUSE_SCL: R14.1, U3.12 (SCL)
/Power Input & Protection/EFUSE_SDA: R13.1, U3.11 (SDA)
/Power Input & Protection/EFUSE_VDD: C14.1, R10.2, U3.9 (VDD)
/Power Input & Protection/LM_VCAP: C11.2, U2.1 (VCAP)
/Power Input & Protection/REVPOL_GATE: Q1.2 (G), U2.5 (GATE)
EFUSE_NFLT: R16.1, U3.13 (FLT); also elsewhere on the board
GND: C10.2, C12.2, C13.2, C14.2, C15.2, C16.2, C17.2, C18.2, C19.2, D10.2, J4.1, R12.2, R17.2, R18.2, U2.2 (GND), U3.5 (GND), U3.21 (WP#); also elsewhere on the board
VIN_RAW: C10.1, C11.1, D10.1, J3.1, Q1.1 (S), TP10.1, U2.3 (EN), U2.6 (ANODE)

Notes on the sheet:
LAYOUT: D10 and C10 directly at J3/J4. Wide pours for VIN_RAW, +VBUS, +VBUS_EFUSE (up to 15 A). LAYOUT: C11 at U2 VCAP/ANODE. U2 close to Q1 gate/source. LAYOUT: C14 at U3 VDD, C16/C17/C18/R17/R18 at their U3 pins, returns to U3 GND. LAYOUT: U3 exposed pad is IN (not GND): via array into the +VBUS 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
C11: VCAP-ANODE, <= 15 V (SNOSD17G)

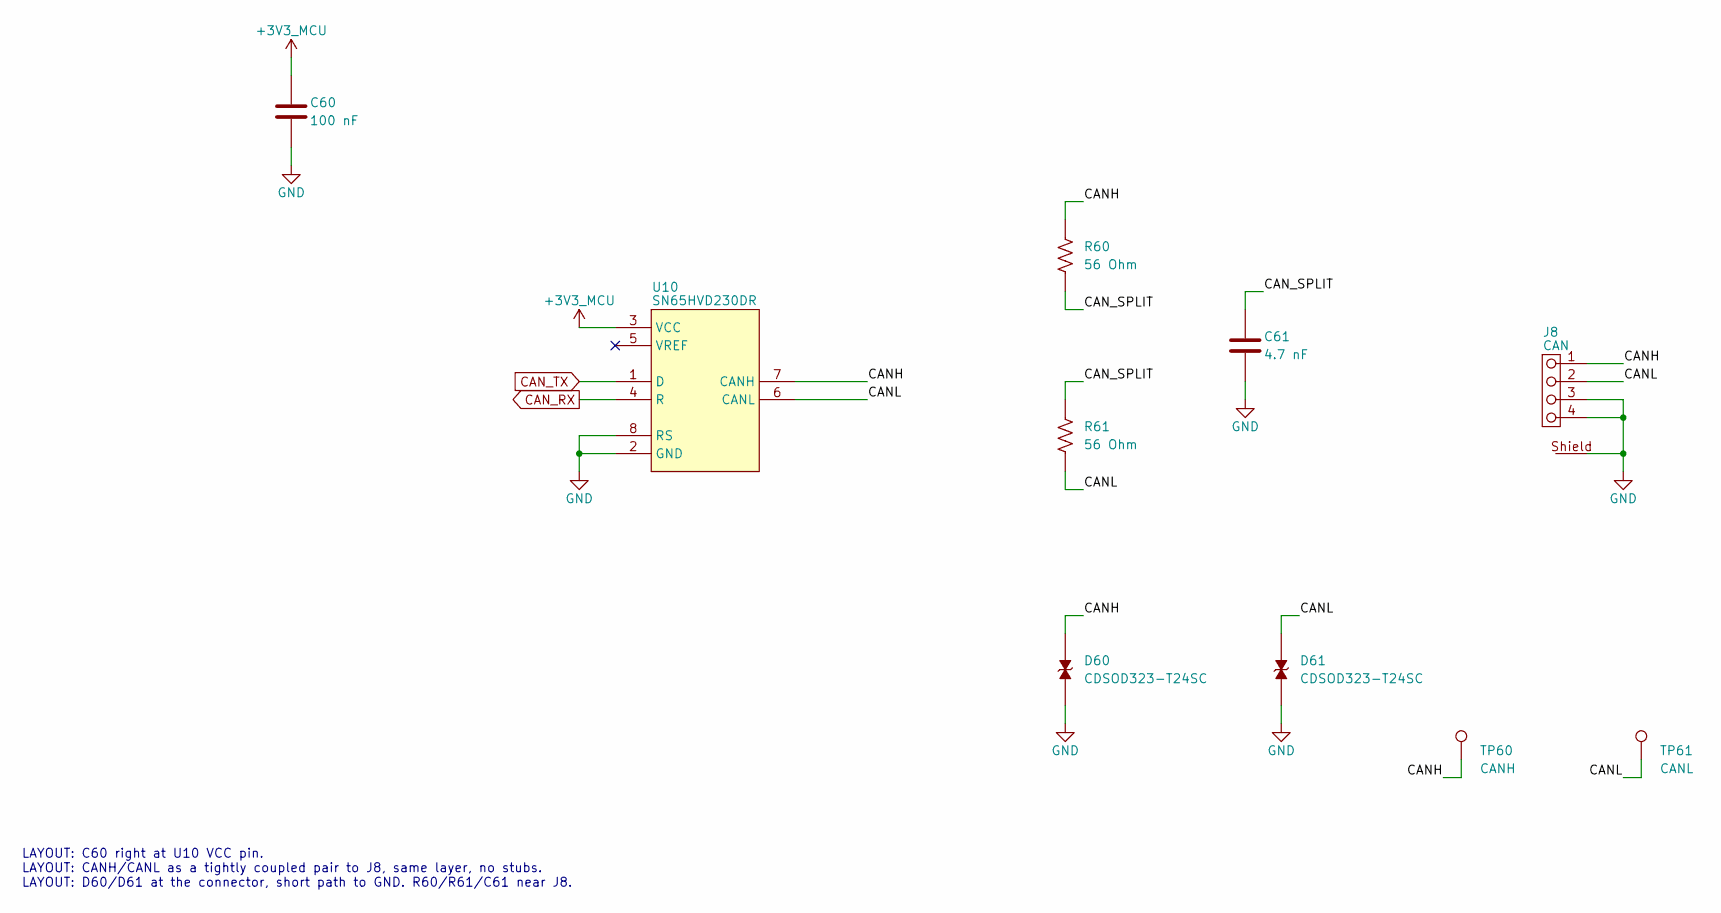
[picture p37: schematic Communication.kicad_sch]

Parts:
C60: 100 nF; 0603_Medium; Tolerance ±10%; Voltage Rating 16V; Digi-Key Number 311-1088-1-ND
C61: 4.7 nF; 0603_Medium; Tolerance ±10%; Voltage Rating 100V; Digi-Key Number 490-4930-1-ND
D60, D61: CDSOD323-T24SC; SOD-323; Breakdown Voltage 26.7V; Clamping Voltage 46.2V; Digi-Key Number CDSOD323-T24SCCT-ND
J8: CAN; 384471-E; Current Rating 12A per Contact; Farnell Number 4060713
R60, R61: 56 Ohm; 0603_Medium; Tolerance ±1%; Mouser Number 708-RMCF0603FT56R0
TP60: CANH; Pad_D1.5mm
TP61: CANL; Pad_D1.5mm
U10: SN65HVD230DR; 8-SOIC; Voltage Rating 3V up to 3.6V; Digi-Key Number 296-11654-1-ND

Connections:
+3V3_MCU: C60.1, U10.3 (VCC); also elsewhere on the board
/Communication/CANH: D60.1, J8.1, R60.1, TP60.1, U10.7 (CANH)
/Communication/CANL: D61.1, J8.2, R61.2, TP61.1, U10.6 (CANL)
/Communication/CAN_SPLIT: C61.1, R60.2, R61.1
CAN_RX: U10.4 (R); also elsewhere on the board
CAN_TX: U10.1 (D); also elsewhere on the board
GND: C60.2, C61.2, D60.2, D61.2, J8.3, J8.4, J8.Shield, U10.2 (GND), U10.8 (RS); also elsewhere on the board

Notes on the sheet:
LAYOUT: C60 right at U10 VCC pin. LAYOUT: CANH/CANL as a tightly coupled pair to J8, same layer, no stubs. LAYOUT: D60/D61 at the connector, short path to GND. R60/R61/C61 near J8.

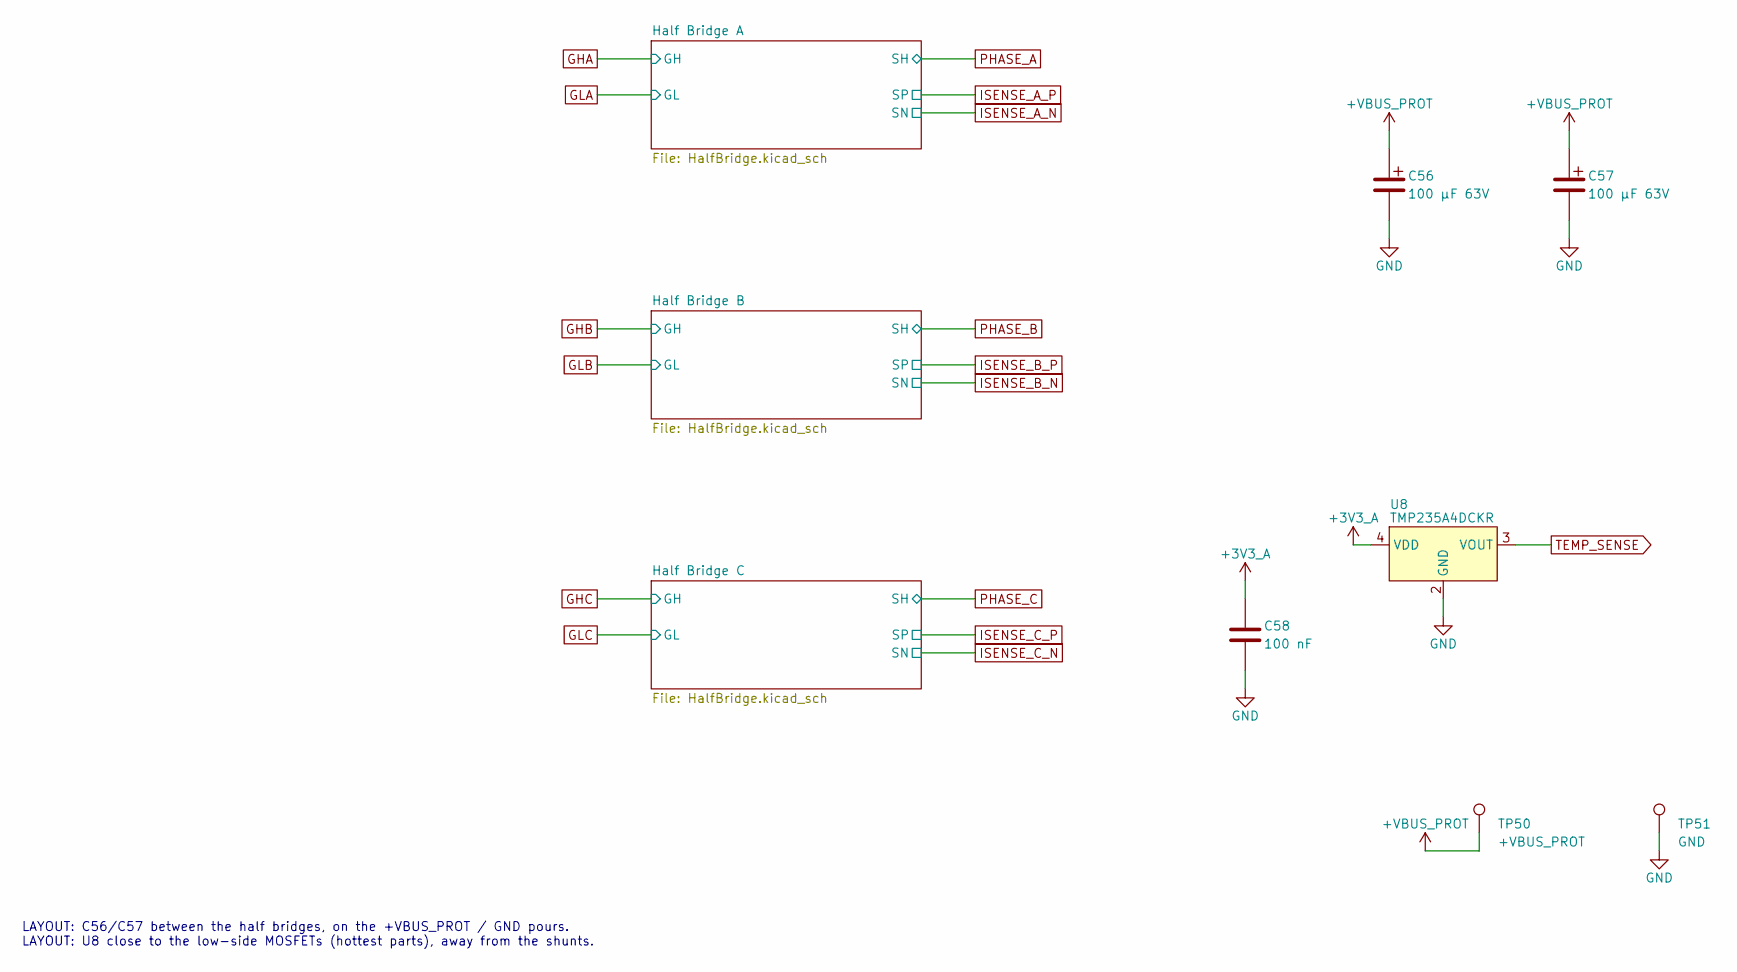
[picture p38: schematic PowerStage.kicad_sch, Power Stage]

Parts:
C56, C57: 100 µF 63V; 8.00x13.50mm; Tolerance ±20%; Voltage Rating 63V; Digi-Key Number 1572-1656-ND
C58: 100 nF; 0603_Medium; Tolerance ±10%; Voltage Rating 16V; Digi-Key Number 311-1088-1-ND
TP50: +VBUS_PROT; Pad_D1.5mm
TP51: GND; Pad_D1.5mm
U8: TMP235A4DCKR; SC-70-5; Supply Voltage Rating 2.3V up to 5.5V; Digi-Key Number 296-50016-1-ND

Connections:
+3V3_A: C58.1, U8.4 (VDD); also elsewhere on the board
+VBUS_PROT: C56.1, C57.1, TP50.1; also elsewhere on the board
GND: C56.2, C57.2, C58.2, TP51.1, U8.2 (GND); also elsewhere on the board
TEMP_SENSE: U8.3 (VOUT); also elsewhere on the board

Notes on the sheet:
LAYOUT: C56/C57 between the half bridges, on the +VBUS_PROT / GND pours. LAYOUT: U8 close to the low-side MOSFETs (hottest parts), away from the shunts.

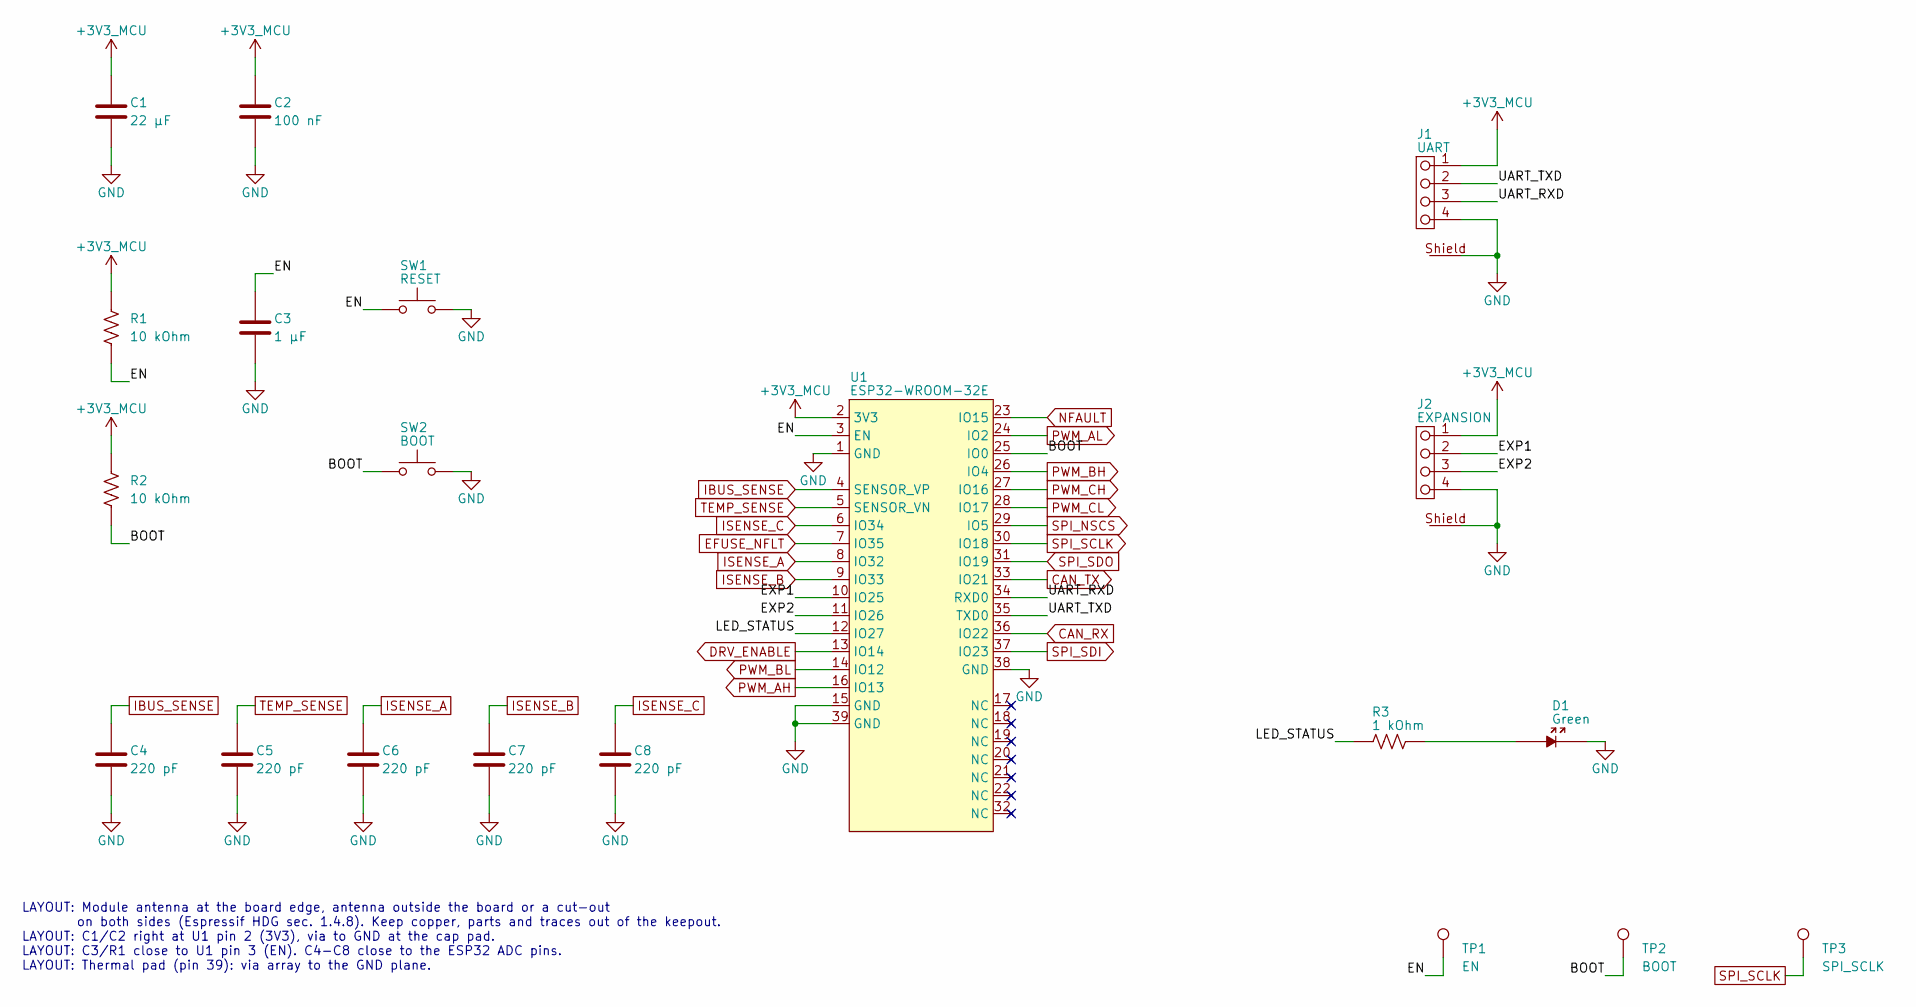
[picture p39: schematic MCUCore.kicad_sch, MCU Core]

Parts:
C1: 22 µF; 0603_Medium; Tolerance ±20%; Voltage Rating 10V; Digi-Key Number 1276-1274-1-ND
C2: 100 nF; 0603_Medium; Tolerance ±10%; Voltage Rating 16V; Digi-Key Number 311-1088-1-ND
C3: 1 µF; 0603_Medium; Tolerance ±10%; Voltage Rating 100V; Digi-Key Number 1276-2883-1-ND
C4, C5, C6, C7, C8: 220 pF; 0603_Medium; Tolerance ±5%; Voltage Rating 50V; Digi-Key Number 1276-1985-1-ND
D1: Green; 0603_Medium; Forward Voltage 3.2V; Current Rating 20mA; Digi-Key Number 732-4971-1-ND
J1: UART; 2147210040; Current Rating 1.5A; Voltage Rating 30V; Mouser Number 538-214721-0040
J2: EXPANSION; 384471-E; Current Rating 12A per Contact; Farnell Number 4060713
R1, R2: 10 kOhm; 0603_Medium; Tolerance ±1%; Mouser Number 603-RC0603FR-0710KL
R3: 1 kOhm; 0603_Medium; Tolerance ±1%; Mouser Number 708-RMCF0603FT1K00
SW1: RESET; TL6330AF200Q; Contact Rating @ Voltage 0.05A @ 32VDC; Digi-Key Number EG5546CT-ND
SW2: BOOT; TL6330AF200Q; Contact Rating @ Voltage 0.05A @ 32VDC; Digi-Key Number EG5546CT-ND
TP1: EN; Pad_D1.5mm
TP2: BOOT; Pad_D1.5mm
TP3: SPI_SCLK; Pad_D1.5mm
U1: ESP32-WROOM-32E; Digi-Key Number 1965-ESP32-WROOM-32E-N4CT-ND

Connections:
+3V3_MCU: C1.1, C2.1, J1.1, J2.1, R1.1, R2.1, U1.2 (3V3); also elsewhere on the board
/MCU Core/BOOT: R2.2, SW2.1, TP2.1, U1.25 (IO0)
/MCU Core/EN: C3.1, R1.2, SW1.1, TP1.1, U1.3 (EN)
/MCU Core/EXP1: J2.2, U1.10 (IO25)
/MCU Core/EXP2: J2.3, U1.11 (IO26)
/MCU Core/LED_STATUS: R3.1, U1.12 (IO27)
/MCU Core/UART_RXD: J1.3, U1.34 (RXD0)
/MCU Core/UART_TXD: J1.2, U1.35 (TXD0)
CAN_RX: U1.36 (IO22); also elsewhere on the board
CAN_TX: U1.33 (IO21); also elsewhere on the board
DRV_ENABLE: U1.13 (IO14); also elsewhere on the board
EFUSE_NFLT: U1.7 (IO35); also elsewhere on the board
GND: C1.2, C2.2, C3.2, C4.2, C5.2, C6.2, C7.2, C8.2, D1.2, J1.4, J1.Shield, J2.4, J2.Shield, SW1.2, SW2.2, U1.1 (GND), U1.15 (GND), U1.38 (GND), U1.39 (GND); also elsewhere on the board
IBUS_SENSE: C4.1, U1.4 (SENSOR_VP); also elsewhere on the board
ISENSE_A: C6.1, U1.8 (IO32); also elsewhere on the board
ISENSE_B: C7.1, U1.9 (IO33); also elsewhere on the board
ISENSE_C: C8.1, U1.6 (IO34); also elsewhere on the board
NFAULT: U1.23 (IO15); also elsewhere on the board
unnamed: D1.1, R3.2
PWM_AH: U1.16 (IO13); also elsewhere on the board
PWM_AL: U1.24 (IO2); also elsewhere on the board
PWM_BH: U1.26 (IO4); also elsewhere on the board
PWM_BL: U1.14 (IO12); also elsewhere on the board
PWM_CH: U1.27 (IO16); also elsewhere on the board
PWM_CL: U1.28 (IO17); also elsewhere on the board
SPI_NSCS: U1.29 (IO5); also elsewhere on the board
SPI_SCLK: TP3.1, U1.30 (IO18); also elsewhere on the board
SPI_SDI: U1.37 (IO23); also elsewhere on the board
SPI_SDO: U1.31 (IO19); also elsewhere on the board
TEMP_SENSE: C5.1, U1.5 (SENSOR_VN); also elsewhere on the board

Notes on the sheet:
LAYOUT: Module antenna at the board edge, antenna outside the board or a cut-out on both sides (Espressif HDG sec. 1.4.8). Keep copper, parts and traces out of the keepout. LAYOUT: C1/C2 right at U1 pin 2 (3V3), via to GND at the cap pad. LAYOUT: C3/R1 close to U1 pin 3 (EN). C4-C8 close to the ESP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

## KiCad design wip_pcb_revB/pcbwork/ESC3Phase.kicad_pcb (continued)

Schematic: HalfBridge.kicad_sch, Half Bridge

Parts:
C50: 10 µF 100V; 1206_Medium; Tolerance ±10%; Voltage Rating 100V; Digi-Key Number 445-C3216X6S2A106K160ACCT-ND
C51: 100 nF 100V; 0603_Medium; Tolerance ±10%; Voltage Rating 100V; Digi-Key Number 1276-6807-1-ND
J5: PHASE; 7770; Current Rating 13A; Mouser Number 534-7770
NT3, NT4: NetTie_2_0.5mm
Q2, Q3: NTMFS006N08MC; 8-PowerTDFN(5x6mm); Digi-Key Number 488-NTMFS006N08MCCT-ND
R50: 2 mOhm; 2512; Tolerance ±5%; Digi-Key Number 18-SSA2512LR002JWRCT-ND

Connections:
+VBUS_PROT: C50.1, C51.1, Q2.3 (D); also elsewhere on the board
/Power Stage/Half Bridge A/LS_SRC: NT3.2, Q3.1 (S), R50.1
GHA: Q2.2 (G); also elsewhere on the board
GLA: Q3.2 (G); also elsewhere on the board
GND: C50.2, C51.2, NT4.2, R50.2; also elsewhere on the board
ISENSE_A_N: NT4.1; also elsewhere on the board
ISENSE_A_P: NT3.1; also elsewhere on the board
PHASE_A: J5.1, Q2.1 (S), Q3.3 (D); also elsewhere on the board

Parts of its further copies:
C52, C54: 10 µF 100V; 1206_Medium; Tolerance ±10%; Voltage Rating 100V; Digi-Key Number 445-C3216X6S2A106K160ACCT-ND
C53, C55: 100 nF 100V; 0603_Medium; Tolerance ±10%; Voltage Rating 100V; Digi-Key Number 1276-6807-1-ND
J6, J7: PHASE; 7770; Current Rating 13A; Mouser Number 534-7770
NT5, NT6, NT7, NT8: NetTie_2_0.5mm
Q4, Q5, Q6, Q7: NTMFS006N08MC; 8-PowerTDFN(5x6mm); Digi-Key Number 488-NTMFS006N08MCCT-ND
R51, R52: 2 mOhm; 2512; Tolerance ±5%; Digi-Key Number 18-SSA2512LR002JWRCT-ND

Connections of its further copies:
+VBUS_PROT: C52.1, C53.1, C54.1, C55.1, Q4.3 (D), Q6.3 (D); also elsewhere on the board
/Power Stage/Half Bridge B/LS_SRC: NT5.2, Q5.1 (S), R51.1
/Power Stage/Half Bridge C/LS_SRC: NT7.2, Q7.1 (S), R52.1
GHB: Q4.2 (G); also elsewhere on the board
GHC: Q6.2 (G); also elsewhere on the board
GLB: Q5.2 (G); also elsewhere on the board
GLC: Q7.2 (G); also elsewhere on the board
GND: C52.2, C53.2, C54.2, C55.2, NT6.2, NT8.2, R51.2, R52.2; also elsewhere on the board
ISENSE_B_N: NT6.1; also elsewhere on the board
ISENSE_B_P: NT5.1; also elsewhere on the board
ISENSE_C_N: NT8.1; also elsewhere on the board
ISENSE_C_P: NT7.1; also elsewhere on the board
PHASE_B: J6.1, Q4.1 (S), Q5.3 (D); also elsewhere on the board
PHASE_C: J7.1, Q6.1 (S), Q7.3 (D); also elsewhere on the board

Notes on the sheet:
LAYOUT: Hot loop: C(10 uF)/C(100 nF) directly across high-side drain and low-side source (shunt GND end); keep this loop as small as possible. LAYOUT: PHASE, +VBUS_PROT and GND as pours on both layers with via arrays (5-10 A). LAYOUT: Kelvin: net ties at the shunt pads, SP/SN as a tight pair to the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

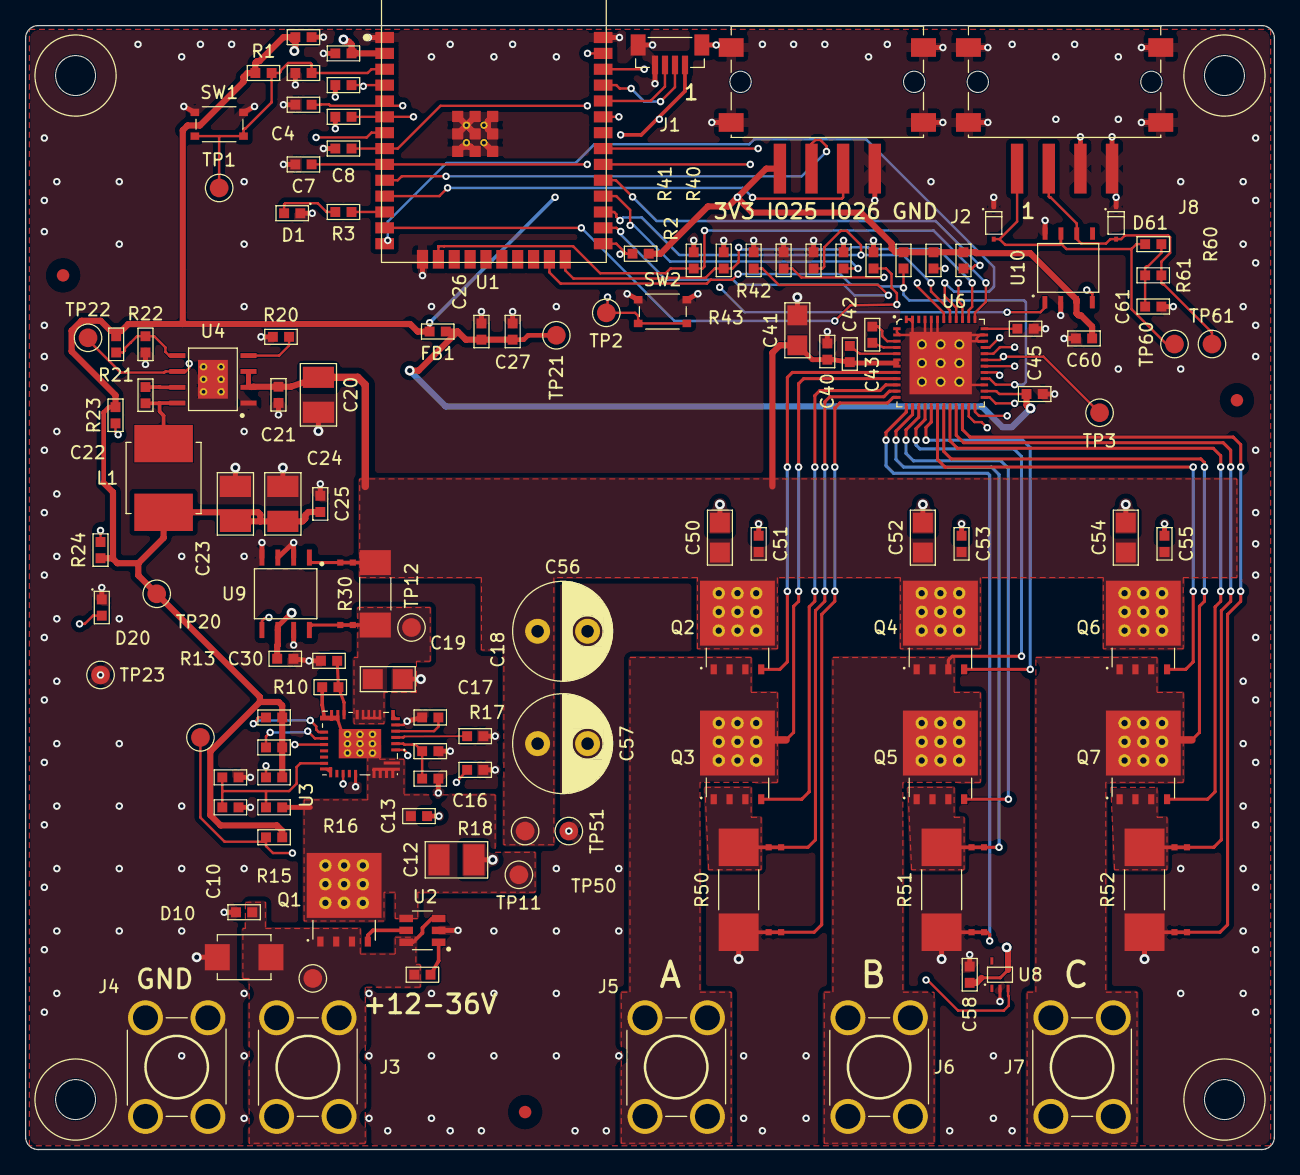
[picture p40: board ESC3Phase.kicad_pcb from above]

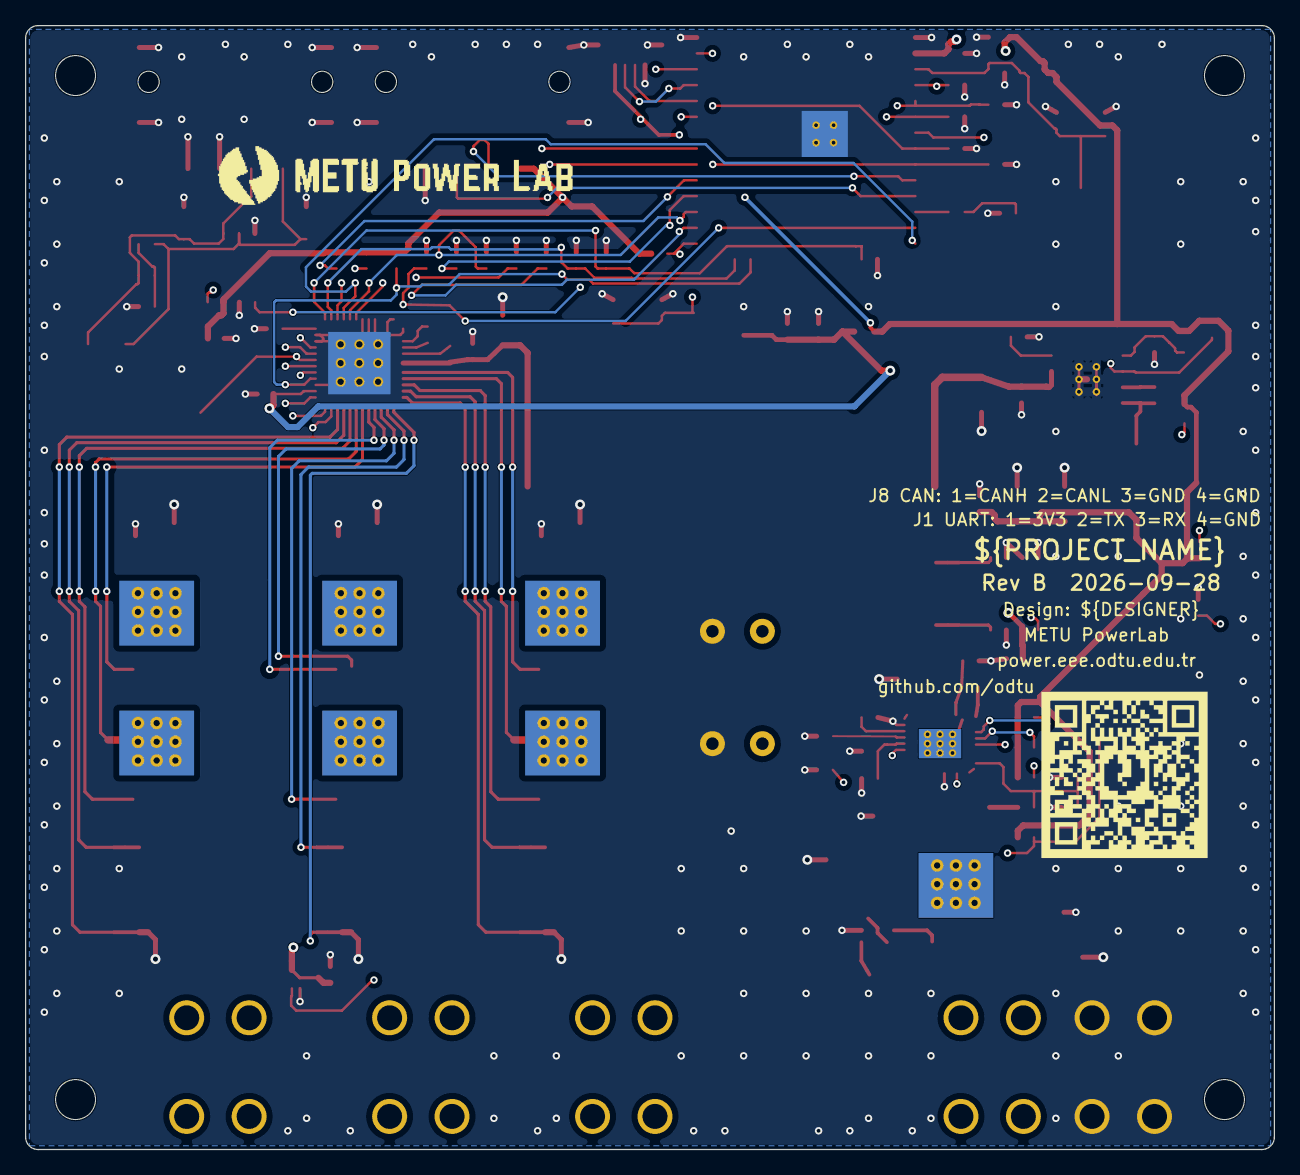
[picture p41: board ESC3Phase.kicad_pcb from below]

Board: 4 copper layers, 100.0 x 90.0 mm, 141 parts (2 on the bottom side), 79 nets.

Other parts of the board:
FID1, FID2, FID3: Fiducial_1mm_Mask2mm
H1, H2, H3, H4: M3_NPTH
LOGO1: METUPowerLab_Logo_30mm
QR1: METUPowerLab_QRCode_13.3mm

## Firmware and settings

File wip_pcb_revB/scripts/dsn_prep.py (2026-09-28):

"""Export the board to Specctra DSN and adapt it for Freerouting:
  - rule areas (fan-out / Kelvin areas) are not keepouts for routing: removed
  - power pours on F.Cu become keepouts (signals cross them on B.Cu), their planes are removed
  - the B.Cu GND plane stays: GND pads already have their vias, the router treats them as connected
  - pour-net pins that the pour already covers are removed from the netlist, so the router only connects
    the pads outside the pour (to the pre-placed port vias)
Usage: python.exe dsn_prep.py <board> <out.dsn>
"""
import sys, re
import pcbnew

T = pcbnew.ToMM


def blocks(text, key):
    """Yield (start, end) of every '(key ...)' block (balanced parentheses, quote-aware)."""
    i = 0
    pat = re.compile(r'\(' + re.escape(key) + r'[\s)]')
    while True:
        m = pat.search(text, i)
        if not m:
            return
        s = m.start(); depth = 0; j = s; q = False
        while j < len(text):
            c = text[j]
            if c == '"':
                q = not q
            elif not q:
                if c == '(':
                    depth += 1
                elif c == ')':
                    depth -= 1
                    if depth == 0:
                        break
            j += 1
        yield s, j + 1
        i = j + 1


def covered_pins(board):
    zones = {}
    for z in board.Zones():
        if z.GetIsRuleArea() or z.GetNetname() in ('', 'GND'):
            continue
        zones.setdefault(z.GetNetname(), []).append(z)
    cov = {}
    for fp in board.GetFootprints():
        for p in fp.Pads():
            zl = zones.get(p.GetNetname())
            if zl and any(z.HitTestFilledArea(z.GetLayer(), p.GetPosition()) for z in zl):
                cov.setdefault(p.GetNetname(), set()).add(f'{fp.GetReference()}-{p.GetNumber()}')
    return cov


def main(board_path, out, relax_hv=0):
    b = pcbnew.LoadBoard(board_path)
    pcbnew.ZONE_FILLER(b).Fill(b.Zones())
    tmp = out + '.raw'
    assert pcbnew.ExportSpecctraDSN(b, tmp)
    t = open(tmp, encoding='utf-8').read()

    # structure: drop keepouts (rule areas), turn non-GND planes into F.Cu keepouts, keep the B.Cu GND plane
    out_parts, last = [], 0
    spans = sorted(list(blocks(t, 'keepout')) + list(blocks(t, 'plane')))
    n_ko = n_pl = 0
    for s, e in spans:
        out_parts.append(t[last:s])
        blk = t[s:e]
        if blk.startswith('(plane'):
            m = re.match(r'\(plane\s+("[^"]*"|\S+)\s+\(polygon\s+(\S+)', blk)
            net, layer = m.group(1).strip('"'), m.group(2)
            if net == 'GND':
                if layer == 'In1.Cu':              # every GND pad has its via: the router sees them joined on L2
                    out_parts.append(blk)
            else:
                out_parts.append('(keepout "" ' + blk[blk.index('(polygon'):])
                n_pl += 1
        else:
            n_ko += 1
        last = e
    out_parts.append(t[last:])
    t = ''.join(out_parts)

    # NPTH holes (mounting holes: 7 mm keepout per rule 3.1; connector pegs: hole + 2 x 0.35 mm) on every copper layer
    ko = []
    for fp in b.GetFootprints():
        for p in fp.Pads():
            if p.GetAttribute() == pcbnew.PAD_ATTRIB_NPTH:
                x, y = pcbnew.ToMM(p.GetPosition().x), pcbnew.ToMM(p.GetPosition().y)
                r = 3.5 if fp.GetReference().startswith('H') else pcbnew.ToMM(p.GetDrillSize().x) / 2 + 0.35
                for L in ('F.Cu', 'In1.Cu', 'In2.Cu', 'B.Cu'):
                    pts = ' '.join(f'{(x + dx) * 1000:.0f} {-(y + dy) * 1000:.0f}' for dx, dy in ((-r, -r), (r, -r), (r, r), (-r, r)))
                    ko.append(f'    (keepout "" (polygon {L} 0 {pts}))')
    st = t.index('(structure')
    i = t.index('(via ', st)                       # after the layer definitions, before the via list
    i = t.rindex('\n', st, i) + 1
    t = t[:i] + '\n'.join(ko) + '\n' + t[i:]

    # network: remove pour-covered pins; nets that are already complete (pre-routing + pours) are not routed
    import subprocess, json as _j
    subprocess.run(['C:/Program Files/KiCad/10.0/bin/kicad-cli.exe', 'pcb', 'drc', '--severity-error', '--format',
                    'json', '-o', out + '.drc.json', board_path], check=True, capture_output=True)
    open_nets = set()
    for x in _j.load(open(out + '.drc.json', encoding='utf-8'))['unconnected_items']:
        for it in x['items']:
            mm = re.search(r'\[(.*?)\]', it['description'])
            if mm:
                open_nets.add(mm.group(1))
    cov = covered_pins(b)
    net_spans = list(blocks(t, 'net'))
    parts, last, pruned = [], 0, 0
    for s, e in net_spans:
        blk = t[s:e]
        m = re.match(r'\(net\s+("[^"]*"|\S+)', blk)
        if not m or '(pins' not in blk:
            continue
        name = m.group(1).strip('"')
        pour_nets = {z.GetNetname() for z in b.Zones() if not z.GetIsRuleArea() and z.GetNetname() not in ('', 'GND')}
        if name not in open_nets and name in pour_nets:   # complete via its pour (a keepout here): one pin only
            ps = blk.index('(pins') + 5
            pe = blk.index(')', ps)
            pins = blk[ps:pe].split()
            blk = blk[:ps] + ' ' + (pins[0] if pins else '') + blk[pe:]
            parts.append(t[last:s]); parts.append(blk); last = e
            continue
        if name in cov:
            ps = blk.index('(pins') + 5
            pe = blk.index(')', ps)
            pins = blk[ps:pe].split()
            keep = [p for p in pins if p.strip('"').split('@')[0] not in cov[name]]   # 'Q2-3@2' = copy of pad 3
            pruned += len(pins) - len(keep)
            blk = blk[:ps] + ' ' + ' '.join(keep) + blk[pe:]
        parts.append(t[last:s]); parts.append(blk); last = e
    parts.append(t[last:])
    t = ''.join(parts)
    if relax_hv:                              # router: IC pins can't be escaped at 0.6 mm; KiCad DRC checks the real rules
        t = re.sub(r'(\(class HV[^(]*(?:\([^()]*(?:\([^()]*\))*[^()]*\)[^(]*)*?\(rule\s*\(width \d+\)\s*\(clearance )600', r'\g<1>' + str(relax_hv), t)
    open(out, 'w', encoding='utf-8').write(t)
    print(f'{out}: removed {n_ko} rule-area keepouts, {n_pl} pours -> keepouts, pruned {pruned} covered pins')


if __name__ == '__main__':
    main(sys.argv[1], sys.argv[2], int(sys.argv[3]) if len(sys.argv) > 3 else 0)

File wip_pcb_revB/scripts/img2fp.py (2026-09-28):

"""Bitmap -> KiCad footprint on F.SilkS (like KiCad's Image Converter): dark pixels become filled rectangles
(horizontal runs merged, identical runs on consecutive rows merged into one rectangle).
Usage: python img2fp.py <image> <out.kicad_mod> <name> <width_mm> [threshold] [--invert-alpha]
"""
import sys, uuid
from PIL import Image


def rects(mask, w, h):
    runs_prev = {}
    out = []
    for y in range(h):
        runs = []
        x = 0
        while x < w:
            if mask[y * w + x]:
                s = x
                while x < w and mask[y * w + x]:
                    x += 1
                runs.append((s, x))
            else:
                x += 1
        cur = {}
        for r in runs:
            if r in runs_prev:
                cur[r] = runs_prev.pop(r)
            else:
                cur[r] = y
        for (s, e), y0 in runs_prev.items():
            out.append((s, y0, e, y))
        runs_prev = cur
    for (s, e), y0 in runs_prev.items():
        out.append((s, y0, e, h))
    return out


def main():
    src, out, name, width = sys.argv[1], sys.argv[2], sys.argv[3], float(sys.argv[4])
    thr = int(sys.argv[5]) if len(sys.argv) > 5 else 128
    im = Image.open(src).convert('RGBA')
    px_mm = 0.1                                            # 0.1 mm grid; features stay >= silk minimum 0.15 mm
    cols = int(round(width / px_mm))
    rows = int(round(im.size[1] * cols / im.size[0]))
    im = im.resize((cols, rows), Image.LANCZOS)
    bg = Image.new('RGBA', im.size, (255, 255, 255, 255))
    g = Image.alpha_composite(bg, im).convert('L')
    mask = [1 if v < thr else 0 for v in g.getdata()]
    rs = rects(mask, cols, rows)
    ox, oy = cols * px_mm / 2, rows * px_mm / 2
    L = [f'(footprint "{name}"', '\t(version 20241229)', '\t(generator "pcbnew")', '\t(generator_version "10.0")',
         '\t(layer "F.Cu")', f'\t(descr "{name}, {cols * px_mm:.1f} x {rows * px_mm:.1f} mm, silkscreen")',
         '\t(attr board_only exclude_from_pos_files exclude_from_bom allow_missing_courtyard)',
         f'\t(property "Reference" "G***" (at 0 {oy + 1.0:.2f} 0) (layer "F.SilkS") (hide yes)'
         f' (uuid "{uuid.uuid4()}") (effects (font (size 1 1) (thickness 0.15))))',
         f'\t(property "Value" "{name}" (at 0 {oy + 2.5:.2f} 0) (layer "F.Fab") (hide yes)'
         f' (uuid "{uuid.uuid4()}") (effects (font (size 1 1) (thickness 0.15))))']
    for x0, y0, x1, y1 in rs:
        a, b, c, d = x0 * px_mm - ox, y0 * px_mm - oy, x1 * px_mm - ox, y1 * px_mm - oy
        L.append(f'\t(fp_poly (pts (xy {a:.3f} {b:.3f}) (xy {c:.3f} {b:.3f}) (xy {c:.3f} {d:.3f}) (xy {a:.3f} {d:.3f}))'
                 f' (stroke (width 0) (type solid)) (fill yes) (layer "F.SilkS") (uuid "{uuid.uuid4()}"))')
    L.append('\t(embedded_fonts no)')
    L.append(')')
    open(out, 'w', encoding='utf-8', newline='\n').write('\n'.join(L) + '\n')
    print(f'{out}: {cols}x{rows} px -> {len(rs)} rectangles, {cols * px_mm:.1f} x {rows * px_mm:.1f} mm')


if __name__ == '__main__':
    main()

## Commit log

2026-09-27 Scaffold ESC3Phase KiCad project
    - Create hardware/ESC3Phase KiCad 10 project (blank schematic + board)
    - Add README describing the 3-phase BLDC ESC project scope
    (ESP32-WROOM-32E, 12-36V in, ~5-10A phase current, UART+CAN)
    - Add .gitignore for KiCad backup/lock files
    [ESC3Phase.kicad_pcb, ESC3Phase.kicad_sch]
2026-09-27 Add hierarchical sheet skeleton and library wiring
    - 6 sub-sheets (Power Supply, MCU Core, Gate Drive, Power Stage,
    Current Sensing, Communication) wired into the root sheet
    - Title blocks + text variables (PROJECT_NAME/DESIGNER/PROJECTNUMBER)
    and METU PowerLab drawing sheet template on every sheet
    - GND (blue)/Power (red) net classes with name-pattern auto-assignment
    - Project-local sym-lib-table/fp-lib-table covering every
    PowerLabKiCadLibraries library plus the new ESP32 library, so the
    schematic tooling can actually place these parts (worked around a
    tool quirk: it only resolves project-scope tables written via the
    register_* tools, not global-scope or hand-edited project tab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
    [Communication.kicad_sch, CurrentSensing.kicad_sch, ESC3Phase.kicad_sch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]
2026-09-27 Populate MCU Core sheet
    ESP32-WROOM-32E (U1) fully wired:
    - Decoupling (C1 100nF + C2 1uF on 3V3/GND)
    - EN: 10k pull-up + 100nF delay cap + manual RESET button
    - BOOT (IO0): 10k pull-up + manual BOOT button
    - nFAULT (IO15): 10k pull-up (also the MTDO safe-boot-strap default)
    - UART0 header (J1, 1x4: 3V3/TX0/RX0/GND) - doubles as flashing +
    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
    [MCUCore.kicad_sch]
2026-09-27 Populate Power Supply sheet
    Full input-protection-through-3.3V chain, wired and datasheet-verified:
    - Input protection: screw terminals, TVS (SMBJ48CA-13-F), high-side
    N-ch ORing/reverse-polarity block (LM5050-1 + NTMFS006N08MC)
    - Input eFuse: TI TPS1689x (PTPS16890VMAR), wired per the real TI
    datasheet (fetched SLVSHO1A directly) in standalone/non-PMBus config
    - EN/UVLO divider computed for ~10V trip, ILIM/IMON set OCP ~18.3A
    - Found and worked around a real vendor symbol defect: pin 20 is
    defined twice (SWEN + WP#) at two different physical locations
    - Buck: LMR38020 (12-36V -> 5V, 2A), wired per the real TI datasheet
    (SNVSC40E) at ~1.1MHz switching, FB divider computed for 5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
    [PowerSupply.kicad_sch]
2026-09-27 Populate Gate Drive sheet (DRV8323R), fix MCU Core PWM pin gap
    - DRV8323RSRGZT (=DRV8323R) fully wired per the real TI datasheet
    (SLVSDJ3D, fetched directly): single shared charge pump (not
    per-phase bootstrap caps as originally assumed), VDD/DVDD internal
    LDO decoupling only, VREF self-referenced, optional 600mA buck
    disabled (nSHD tied to GND), CAL tied to GND
    - Caught and fixed a real gap before it became a wiring mistake: the
    chip needs 6 direct hardware PWM pins (INHA/INLA/INHB/INLB/INHC/
    INLC) in addition to SPI - missed in the first pass. Also removed a
    fictitious 'nSLEEP' pin that doesn't exist on this part (ENABLE
    alone controls sleep). Reassigned MCU Core GPIOs acco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
    [GateDrive.kicad_sch, MCUCore.kicad_sch]
2026-09-27 Populate Power Stage sheet
    - 3x half-bridge (NTMFS006N08MC x6), driven by DRV8323 GHx/GLx/SHx
    - 3x Kelvin current shunts (2 mOhm 1W) - found and worked around
    another vendor-symbol quirk: the shunt is a real 4-terminal Kelvin
    part with force+sense pads sharing pin numbers, needing a second
    label pass per shunt (same class of issue as DRV8323's WP#/SWEN,
    but this one is intentional/correct part modeling, not a bug)
    - TMP235 temperature sensor near the FET cluster
    - 3x phase output screw terminals
    - Hot-loop + DC-bus bulk decoupling
    - LAYOUT notes for Kelvin sensing and hot-loop caps per design rules
    [PowerStage.kicad_sch]
2026-09-27 Populate Current Sensing + Communication sheets; schematic complete
    Current Sensing:
    - DC-bus shunt (5 mOhm, in series after the eFuse - required renaming
    the eFuse OUT net to +VBUS_EFUSE_OUT so the shunt sits properly
    in-line ahead of +VBUS_PROT)
    - INA240 total-bus current sense, unidirectional config, -> MCU ADC
    Communication:
    - SN65HVD230 CAN transceiver (3.3V native) on ESP32 TWAI pins
    - Per-line TVS (SP0115-01UTG) on CANH/CANL
    - 4-pin bus connector (CANH/CANL/GND/+VBUS_PROT)
    Whole-hierarchy ERC (all 6 sheets + root) now down to 3 residual
    errors, all the same benign/expected 'two power_out pins on one net'
    pattern (datasheet-recommended parallel pins, or a PWR_FLAG sharing
    a net w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
    [Communication.kicad_sch, CurrentSensing.kicad_sch, GateDrive.kicad_sch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]
2026-09-27 PCB layout: board outline, mounting holes, footprint placement, copper pours, phase-output routing
    - 100x115mm 2-layer board, 4x M3 mounting holes, design rules per PowerLab spec
    - All 55 schematic components synced to board with real footprints
    - Auto-placed via force-directed placement with locked connector/MCU anchors
    - GND pour (both layers) + localized pours for VIN_RAW/+VBUS/+VBUS_EFUSE_OUT/+VBUS_PROT/+5V_LOGIC
    - Routed the 3 critical phase-output traces (SHA/SHB/SHC, 2mm wide)
    - Documented full PCB status in ARCHITECTURE.md: NOT yet fab-ready (732 DRC
    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
    [Communication.kicad_sch, CurrentSensing.kicad_sch, ESC3Phase.kicad_pcb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]
2026-09-27 PCB: fix all real courtyard overlaps, route every net, add +3V3_MCU pour
    - Resolved all 44 real footprint/pad collisions via targeted placement
    fixes (verified pad-by-pad); 5 residual flags are a vendor-footprint
    bounding-box artifact on the PowerTDFN MOSFETs, not real collisions
    - Hid the 4 mounting holes' oversized reference/value silkscreen text
    that was hanging off the board edge
    - Added a +3V3_MCU copper pour (18-pad fanout, same pattern as the
    other power rails)
    - Routed every remaining net on the board: PWM gate-drive x6 + pulldowns,
    ENABLE/nFAULT/EN, SPI, CAN, UART, ADC sense lines, buck converter
    network, all 9 eFuse config lines, charge pump, VREF/DVDD decouple,
    BOOT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
    [ESC3Phase.kicad_pcb]
2026-09-27 Schematic Rev B: full rebuild per METU PowerLab rules
    Rev A was withdrawn: labels stuck on pins created real net shorts
    (+5V_LOGIC with the 36 V bus, INHA and EFUSE_IMON with GND) and several
    circuits contradicted their datasheets.
    Rev B: real wires and power symbols on the 2.54 mm grid, hierarchical sheets
    (half bridge reused 3x), library values, LAYOUT notes, root page with specs
    and block diagram. Circuit fixes: DRV8323 VREF driven, unused buck tied to
    GND, INA240A1, LM74700-Q1 reverse polarity, SMBJ36CA, eFuse per datasheet,
    direct 3.3 V buck, 4.7 uH/8.1 A inductor, 2512 shunts with net-tie Kelvin,
    24 V CAN ESD. kicad-cli ERC: 0 errors; netlist matches intent on all nets.
    Old board and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
    [Communication.kicad_sch, CurrentSensing.kicad_sch, ESC3Phase.kicad_pcb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]
2026-09-28 PCB Rev B: 4-layer layout, fully routed, kicad-cli DRC clean
    - 100 x 90 mm, 4 layers (L2 solid GND), 1.6 mm, 1 oz, PCBWay standard 4-layer spec
    - Placement per METU PowerLab rule 3.2: logic on top, input chain on the left, bus band over three
    half-bridge columns, input and phase terminals on the bottom edge, every decoupling cap at its pin
    - Power pours for the bus, phases, low-side sources and input chain; GND on all layers with a via at
    every GND pad and stitching vias
    - DRV8323 gate drive hand-routed (gate + phase-sense pairs, 0.6 mm to everything else)
    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
    [ESC3Phase.kicad_pcb]
2026-09-28 Project settings saved by KiCad; schematic connection grid 2.54 mm
    Opening the project in KiCad 10 filled in the schematic defaults (annotation, BOM, drawing
    defaults) and the local view state. Net classes, HV patterns and text variables are unchanged.
    The connection grid default (50 mil) is set to 100 mil = 2.54 mm, the grid the schematic is
    drawn on (METU PowerLab rule 1.4). kicad-cli: DRC 0 errors / 0 unconnected / 0 parity, ERC 0 errors.
2026-09-28 Fab outputs Rev B: Gerber + drill zip, BOM, position file, assembly drawings
    - hardware/fab: Gerbers (4 copper layers, mask, paste, silk, outline), Excellon PTH/NPTH with
    maps, PCBWay upload zip, grouped BOM (MPN, manufacturer, package, SMD/THT, Digi-Key, Mouser,
    notes), SMD position file, top/bottom assembly drawings, order spec in fab/README.md
    - Board: drill/place origin set to the bottom-left board corner so all outputs share one origin
    (kicad-cli DRC with parity still 0 errors / 0 unconnected / 0 parity)
    - BOM notes: order the 1 uF parts by MPN (library distributor numbers point to another part);
    CAN split termination only on the two bus-end nodes
    - README / ARCHITECTURE: fab ou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
    [ESC3Phase-B_Cu.gbl, ESC3Phase-B_Mask.gbs, ESC3Phase-B_Paste.gbp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]
2026-10-03 Rename project to PCBDesignWClaude; add Rev B work files and presentation
    - README heading uses the new repo name (moved to odtu/PCBDesignWClaude)
    - wip_pcb_revB/: Rev B build/route/render scripts, intermediate boards,
    Freerouting logs and library change files
    - Presentation.pptx
    - KiCad project local settings
    [Communication.kicad_sch, CurrentSensing.kicad_sch, ESC3Phase.kicad_pcb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]
